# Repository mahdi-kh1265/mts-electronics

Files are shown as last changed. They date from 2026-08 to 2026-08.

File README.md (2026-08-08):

# mts-electronics

Analog RF, photodetector, and demodulation electronics for POSM's modulation-transfer spectroscopy (MTS) laser-locking system.

This repository contains two custom PCBs:

1. **`mts-clk`** — 10 MHz RF distribution and phase-control board for the EOM drive and MTS demodulation local oscillator.
2. **`mts-demod`** — photodiode front end, RF conditioning, analog mixer demodulation, and baseband error-signal generation.

The boards form the analog front end of POSM's rubidium MTS frequency lock.

---

## System Overview

# 1. `mts-clk` — 10 MHz Clock / Phase-Control Board

`mts-clk` takes a common 10 MHz RF source and generates the two coherent RF signals needed by the spectroscopy system:

* **EOM path** — drives the modulation chain associated with the electro-optic modulator.
* **DEMOD path** — provides the coherent local oscillator used by the analog MTS mixer.

Using a common source preserves coherence between modulation and demodulation.

# 2. `mts-demod` — Photodiode and Analog Demodulator

`mts-demod` converts the optical MTS signal into a low-frequency analog error signal suitable for digitization and feedback.

The board includes:

* FDS010 photodiode interface
* reverse-bias circuitry
* OPA858 transimpedance amplifier
* OPA695 second-stage RF amplifier
* 25 MHz RF cleanup filters
* RF splitting / diagnostic outputs
* conditioned 10 MHz LO path
* Mini-Circuits ADE-1+ mixer
* Mini-Circuits PLP-5+ post-mixer low-pass filter
* raw and demodulated monitor outputs

# 3. Repository Structure

```text
mts-electronics/
│
├── mts-clk/
│   ├── mts-clk.kicad_sch
│   ├── mts-clk.kicad_pcb
│   ├── mts-clk.kicad_pro
│   ├── libraries/
│   └── gerbers/
│
├── mts-demod/
│   ├── mts-demod.kicad_sch
│   ├── mts-demod.kicad_pcb
│   ├── mts-demod.kicad_pro
│   └── libraries/
│
├── LICENSE
└── README.md
```

The projects are currently stored in **KiCad 10** format.

---

# 4. Major Components

| Function | Part | Board |
| --- | --- | --- |
| RF power splitter | Mini-Circuits TCP-2-10X | `mts-clk` |
| EOM-path RF amplifier | ADI LTC6433-15 | `mts-clk` |
| DEMOD-path RF amplifier | ADI LTC6433-15 | `mts-clk` |
| Voltage-controlled RF phase shifter | Mini-Circuits SCPHS-13.6+ | `mts-clk` |
| Phase-control buffer | TI OPA197 | `mts-clk` |
| Photodiode | Thorlabs FDS010 | `mts-demod` |
| First-stage TIA | TI OPA858 | `mts-demod` |
| Second-stage amplifier | TI OPA695 | `mts-demod` |
| LO gain block | Mini-Circuits GVA-81 | `mts-demod` |
| Mixer | Mini-Circuits ADE-1+ | `mts-demod` |
| Post-mixer LPF | Mini-Circuits PLP-5+ | `mts-demod` |

Refer to the KiCad schematics for current component values and complete BOM information.

---

# 5. Bring-Up Sequence

These boards should be characterized independently before being connected to the complete laser lock.

## `mts-clk`

1. Verify resistance from each supply rail to ground before applying power.
2. Power the board with no external RF connections.
3. Verify all supply rails and amplifier bias conditions.
4. Apply a known 10 MHz RF input.
5. Measure the EOM output with an oscilloscope or spectrum analyzer.
6. Measure the DEMOD output.
7. Sweep the analog phase-control voltage.
8. Verify phase variation at 10 MHz relative to the EOM output.
9. Verify output amplitude remains within the intended range across the useful phase-control range.
10. Characterize phase versus control voltage and save the calibration curve.

## `mts-demod`

1. Verify all power rails before installing/connecting sensitive external hardware.
2. Verify photodiode reverse bias.
3. Illuminate the FDS010 with a controlled optical signal.
4. Measure the OPA858 TIA output.
5. Verify the OPA695 second-stage gain.
6. Verify the 25 MHz cleanup-filter response.
7. Apply a known 10 MHz DEMOD/LO signal.
8. Verify the GVA-81 LO chain.
9. Verify adequate LO drive at the ADE-1+.
10. Observe the raw mixer IF.
11. Verify the PLP-5+ output.
12. Sweep relative RF/LO phase and confirm the expected quadrature dependence.
13. Only after analog characterization, connect the ADC / FPGA system.

---

# 10. Characterization Data to Add

The schematic captures the intended design. Measured hardware performance should be added separately once boards are assembled.

Useful measurements include:

### CLK board

* EOM output power at 10 MHz
* DEMOD output power at 10 MHz
* EOM-to-DEMOD relative phase range
* phase versus control voltage
* amplitude versus phase-control voltage
* harmonic distortion
* broadband noise
* output return loss / matching

### DEMOD board

* TIA transimpedance
* TIA noise spectral density
* complete photodiode-path gain
* 25 MHz filter response
* mixer conversion gain/loss
* LO level at ADE-1+
* baseband transfer function
* analog error-signal noise
* output offset
* usable MTS discriminator slope
* channel saturation limits

Measured data should eventually be stored under a dedicated directory such as:

```text
measurements/
├── mts-clk/
│   ├── phase_vs_control_voltage.csv
│   ├── output_spectrum/
│   └── network_analyzer/
│
└── mts-demod/
    ├── tia_noise/
    ├── rf_transfer_function/
    ├── mixer_characterization/
    └── mts_error_signal/
```
# License

Released under the license included in [`LICENSE`](LICENSE).

---

## POSM

**Photonics and Optical Sciences Club at Minnesota**
University of Minnesota

[POSM website](https://posmphotonics.org/)

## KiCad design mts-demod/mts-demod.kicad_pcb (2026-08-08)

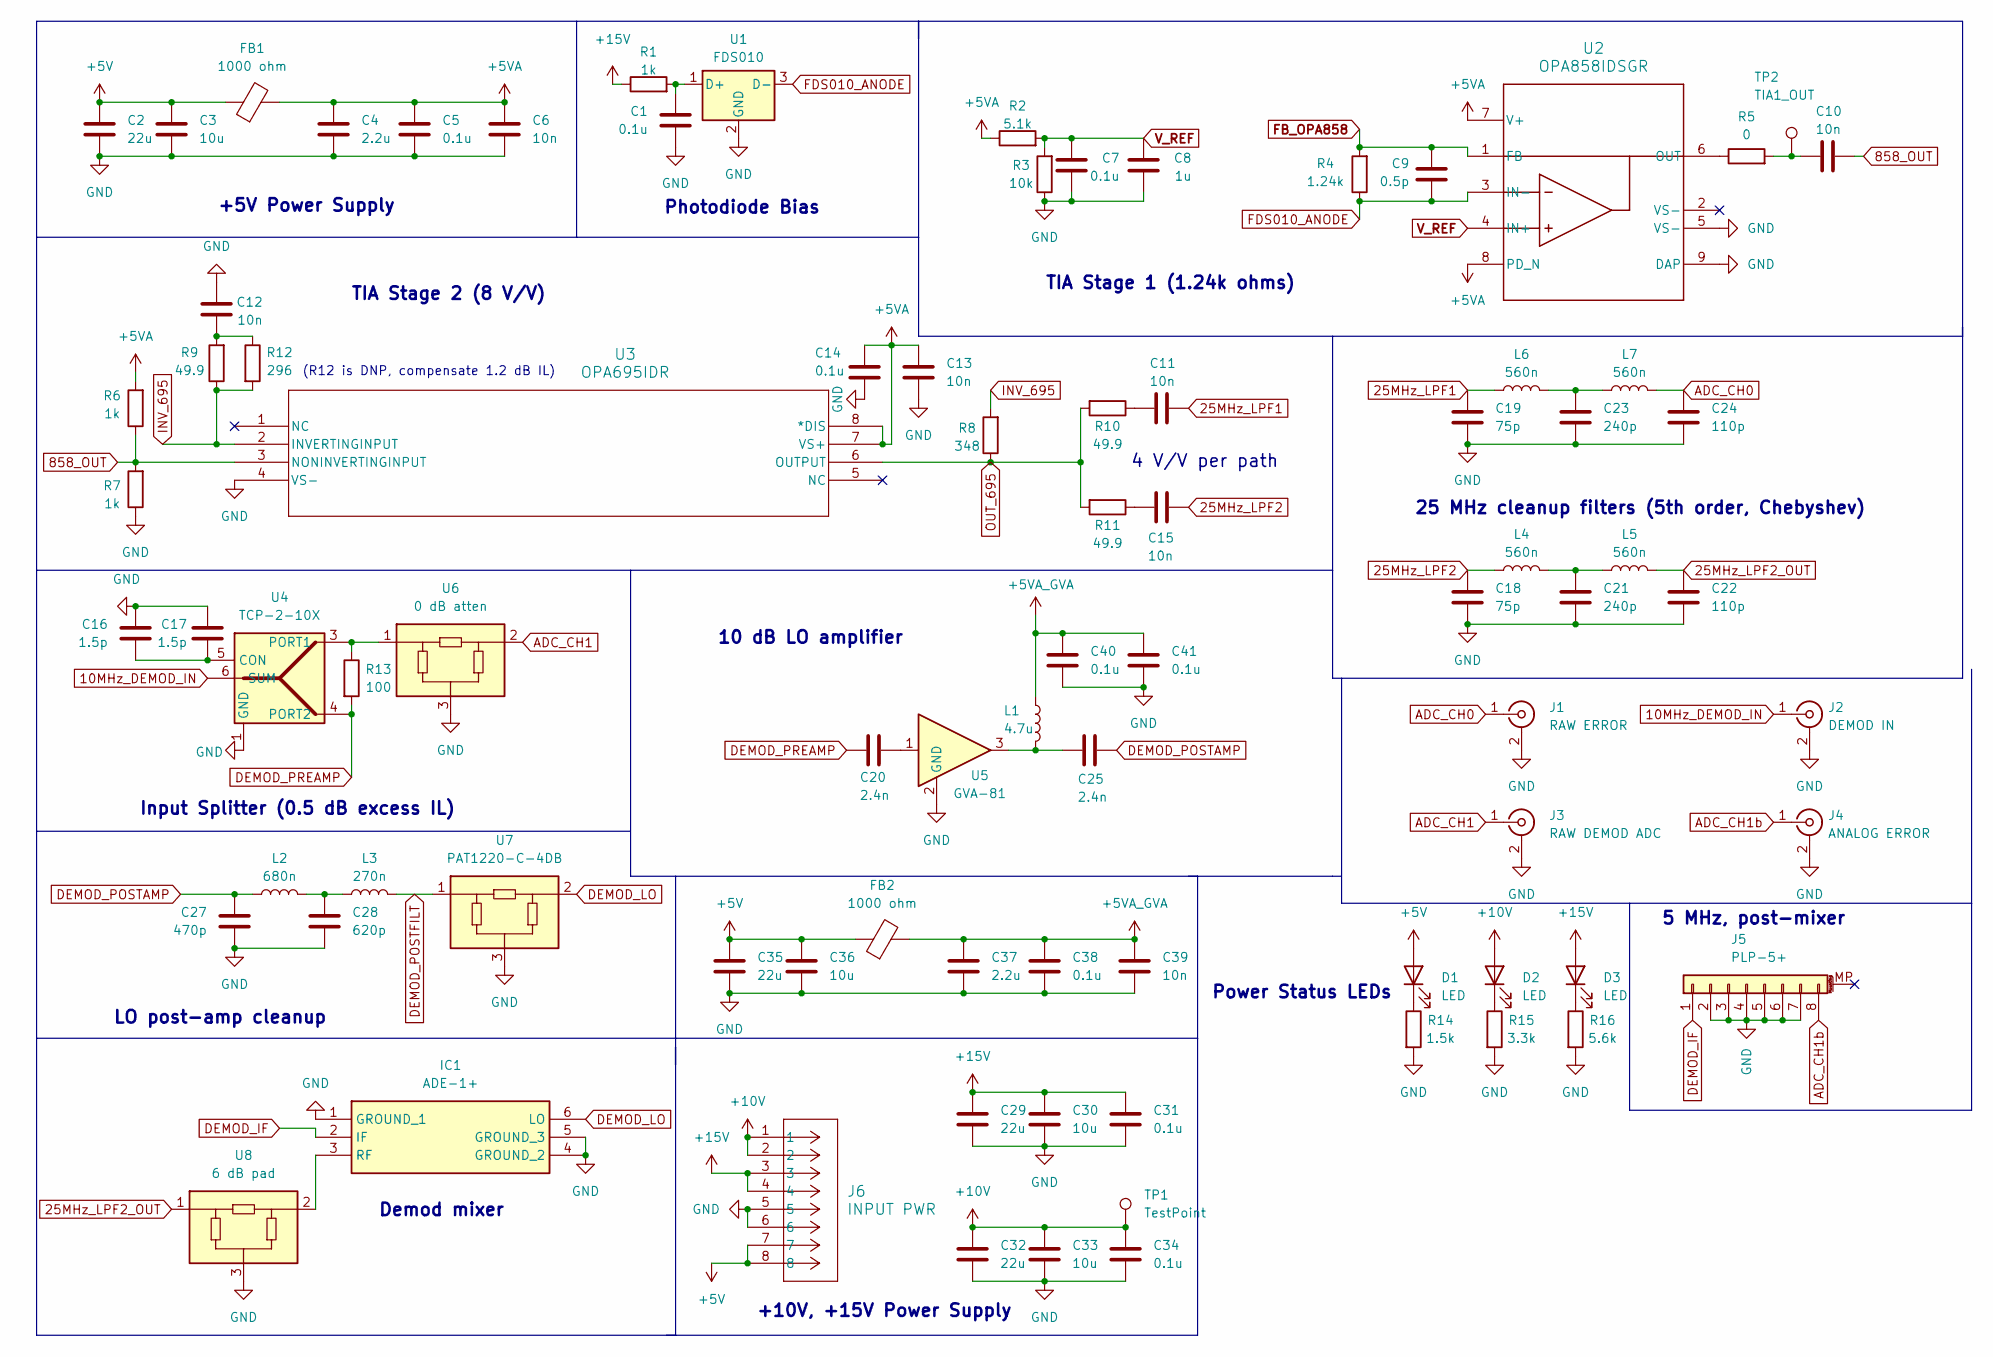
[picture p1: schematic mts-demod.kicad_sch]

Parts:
C1, C5, C7, C14, C31, C34, C38, C40, C41: 0.1u; C_0603_1608Metric
C2, C29, C32, C35: 22u; C_0805_2012Metric
C3, C30, C33, C36: 10u; C_0805_2012Metric
C4, C37: 2.2u; C_0603_1608Metric
C6, C10, C11, C12, C13, C15, C39: 10n; C_0402_1005Metric
C8: 1u; C_0603_1608Metric
C9: 0.5p; C_0402_1005Metric
C16, C17: 1.5p; C_0402_1005Metric
C18: 75p; C_0805_2012Metric
C19: 75p; C_0402_1005Metric
C20, C25: 2.4n; C_0402_1005Metric
C21: 240p; C_0805_2012Metric
C22: 110p; C_0805_2012Metric
C23: 240p; C_0402_1005Metric
C24: 110p; C_0402_1005Metric
C27: 470p; C_0805_2012Metric
C28: 620p; C_0805_2012Metric
D1, D2, D3: LED; LED_0603_1608Metric
FB1, FB2: 1000 ohm; L_0805_2012Metric
IC1: ADE-1+; ADE1; Mouser Part Number 139-ADE-1
J1: RAW ERROR; CONN_SMA-J-P-H-ST-TH1_SAI
J2: DEMOD IN; CONN_SMA-J-P-H-ST-TH1_SAI
J3: RAW DEMOD ADC; CONN_SMA-J-P-H-ST-TH1_SAI
J4: ANALOG ERROR; CONN_SMA-J-P-H-ST-TH1_SAI
J5: PLP-5+; MINI-CIRCUITS_A01_CERN
J6: INPUT PWR; CONN_SD-43045-005_08_MOL
L1: 4.7u; L_0603_1608Metric
L2: 680n; L_0805_2012Metric
L3: 270n; L_0805_2012Metric
L4, L5, L6, L7: 560n; L_0805_2012Metric
R1, R6, R7: 1k; C_0603_1608Metric
R2: 5.1k; R_0603_1608Metric
R3: 10k; R_0603_1608Metric
R4: 1.24k; R_0603_1608Metric
R5: 0; R_0402_1005Metric
R8: 348; R_0402_1005Metric
R9: 49.9; C_0603_1608Metric
R10, R11: 49.9; R_0402_1005Metric
R12: 296; C_0603_1608Metric
R13: 100; C_0603_1608Metric
R14: 1.5k; C_0603_1608Metric
R15: 3.3k; C_0603_1608Metric
R16: 5.6k; C_0603_1608Metric
TP1: TestPoint; TestPoint_Keystone_5015_Micro_Mini
TP2: TIA1_OUT; TestPoint_Keystone_5015_Micro_Mini
U1: FDS010; TO-39-3
U2: OPA858IDSGR; DSG0008A
U3: OPA695IDR; D8
U4: TCP-2-10X; Mini-Circuits_DB1627
U5: GVA-81; SOT-89-3
U6: 0 dB atten; RF_Attenuator_Susumu_PAT1220
U7: PAT1220-C-4DB; RF_Attenuator_Susumu_PAT1220
U8: 6 dB pad; RF_Attenuator_Susumu_PAT1220

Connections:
10MHz_DEMOD_IN: J2.1 (In), U4.6 (SUM)
25MHz_LPF1: C11.2, C19.1, L6.1
25MHz_LPF2: C15.2, C18.1, L4.1
25MHz_LPF2_OUT: C22.1, L5.2, U8.1
858_OUT: C10.2, R6.1, R7.2, U3.3 (NONINVERTINGINPUT)
+5V: C2.1, C3.1, C35.1, C36.1, D1.2 (A), FB1.1, FB2.1, J6.7, J6.8; also elsewhere on the board
+5VA: C4.1, C5.1, C6.1, C13.1, C14.2, FB1.2, R2.1, R6.2, U2.7 (V+), U2.8 (PD_N), U3.7 (VS+), U3.8 (*DIS)
+5VA_GVA: C37.1, C38.1, C39.1, C40.1, C41.1, FB2.2, L1.1
+10V: C32.1, C33.1, C34.1, D2.2 (A), J6.1, J6.2, TP1.1; also elsewhere on the board
+15V: C29.1, C30.1, C31.1, D3.2 (A), J6.3, J6.4, R1.1; also elsewhere on the board
ADC_CH0: C24.1, J1.1 (In), L7.2
ADC_CH1: J3.1 (In), U6.2
ADC_CH1b: J4.1 (In), J5.8
DEMOD_IF: IC1.2 (IF), J5.1
DEMOD_LO: IC1.6 (LO), U7.2
DEMOD_POSTAMP: C25.1, C27.2, L2.1
DEMOD_POSTFILT: L3.2, U7.1
DEMOD_PREAMP: C20.2, R13.2, U4.4 (PORT2)
FB_OPA858: C9.2, R4.2, U2.1 (FB)
FDS010_ANODE: C9.1, R4.1, U1.3 (D-), U2.3 (IN-)
GND: C1.2, C2.2, C3.2, C4.2, C5.2, C6.2, C7.2, C8.2, C12.1, C13.2, C14.1, C16.2, C17.2, C18.2, C19.2, C21.2, C22.2, C23.2, C24.2, C27.1, C28.1, C29.2, C30.2, C31.2, C32.2, C33.2, C34.2, C35.2, C36.2, C37.2, C38.2, C39.2, C40.2, C41.2, IC1.1 (GROUND_1), IC1.4 (GROUND_2), IC1.5 (GROUND_3), J1.2 (Ext), J1.3, J1.4, J1.5, J2.2 (Ext), J2.3, J2.4, J2.5, J3.2 (Ext), J3.3, J3.4, J3.5, J4.2 (Ext), J4.3, J4.4, J4.5, J5.2, J5.3, J5.4, J5.5, J5.6, J5.7, J6.5, J6.6, R3.1, R7.1, R14.2, R15.2, R16.2, U1.2 (GND), U2.5 (VS-), U2.9 (DAP), U3.4 (VS-), U4.1 (GND), U5.2 (GND_2), U6.3, U7.3, U8.3
INV_695: R8.2, R9.1, R12.2, U3.2 (INVERTINGINPUT)
unnamed 22: C10.1, R5.2, TP2.1; also elsewhere on the board
unnamed: C11.1, R10.1
unnamed: C12.2, R9.2, R12.1
unnamed: C15.1, R11.1
unnamed: C20.1, U5.1
unnamed: C21.1, L4.2, L5.1
unnamed: C23.1, L6.2, L7.1
unnamed: C25.2, L1.2, U5.3
unnamed: C28.2, L2.2, L3.1
unnamed 31: D1.1 (K), R14.1; also elsewhere on the board
unnamed 32: D2.1 (K), R15.1; also elsewhere on the board
unnamed 33: D3.1 (K), R16.1; also elsewhere on the board
unnamed: IC1.3 (RF), U8.2
unnamed: C1.1, R1.2, U1.1 (D+)
unnamed: R5.1, U2.6 (OUT)
unnamed: R13.1, U4.3 (PORT1), U6.1
OUT_695: R8.1, R10.2, R11.2, U3.6 (OUTPUT)
V_REF: C7.1, C8.1, R2.2, R3.2, U2.4 (IN+)

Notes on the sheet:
(R12 is DNP, compensate 1.2 dB IL)
+10V, +15V Power Supply
+5V Power Supply
Photodiode Bias
Power Status LEDs
25 MHz cleanup filters (5th order, Chebyshev)
10 dB LO amplifier
4 V/V per path
LO post-amp cleanup
TIA Stage 2 (8 V/V)
TIA Stage 1 (1.24k ohms)
5 MHz, post-mixer
Input Splitter (0.5 dB excess IL)
Demod mixer

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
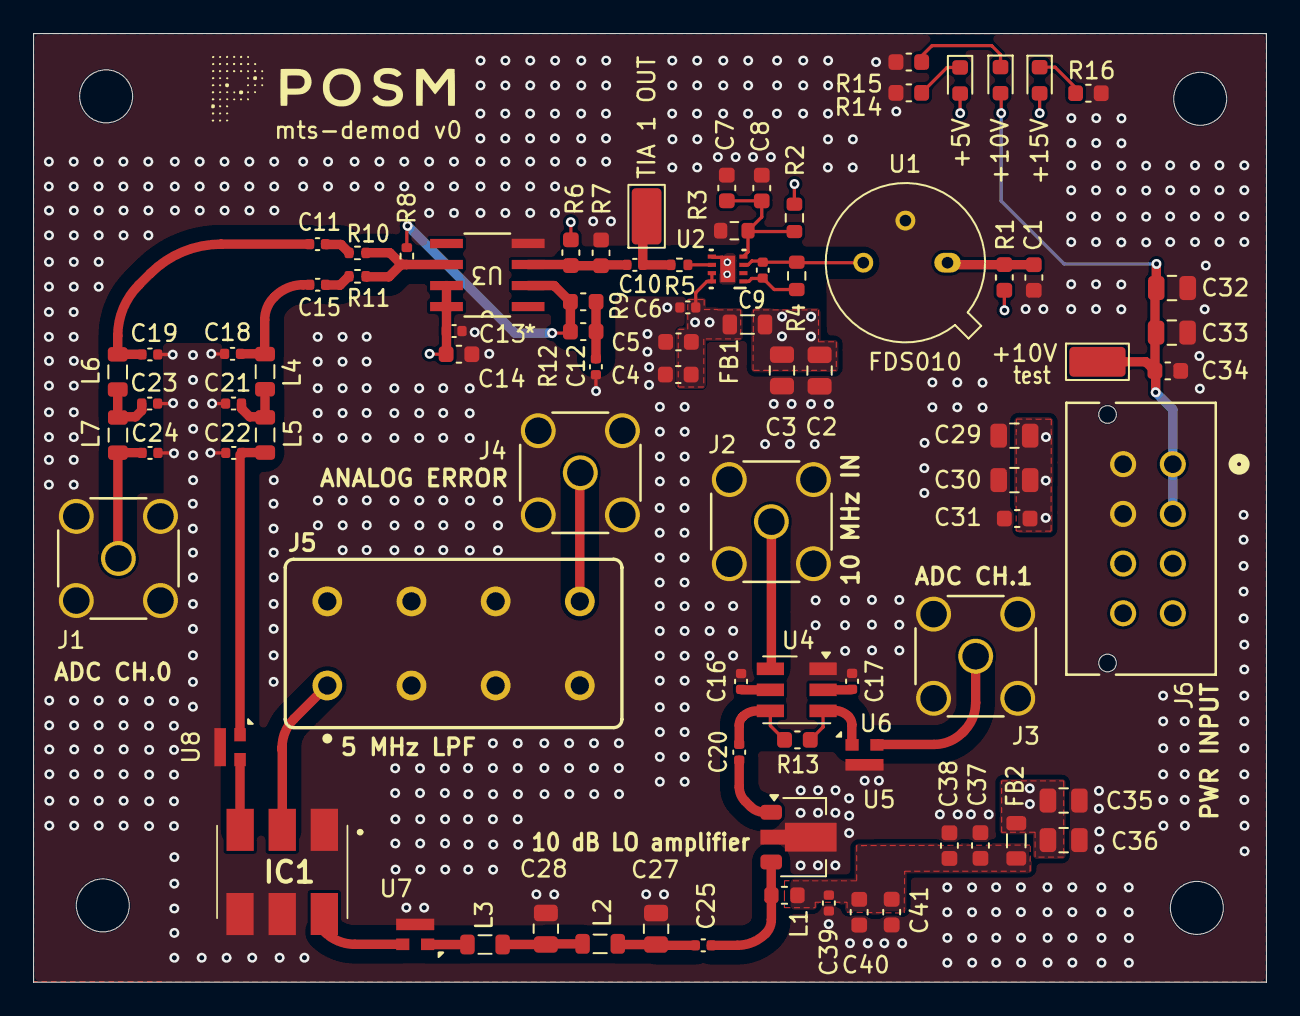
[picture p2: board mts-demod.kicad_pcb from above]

Board: 4 copper layers, 74.4 x 57.3 mm, 85 parts (0 on the bottom side), 42 nets.

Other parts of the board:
+5V, +10V#2, +15V: LED; LED_0603_1608Metric
+10V: TestPoint; TestPoint_Keystone_5015_Micro_Mini
TIA 1 OUT: TIA1_OUT; TestPoint_Keystone_5015_Micro_Mini

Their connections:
+5V: +5V.2 (A); also elsewhere on the board
+10V: +10V.1 (1_1), +10V#2.2 (A); also elsewhere on the board
+15V: +15V.2 (A); also elsewhere on the board
unnamed 22: TIA 1 OUT.1 (1_1); also elsewhere on the board
unnamed 31: +5V.1 (K); also elsewhere on the board
unnamed 32: +10V#2.1 (K); also elsewhere on the board
unnamed 33: +15V.1 (K); also elsewhere on the board

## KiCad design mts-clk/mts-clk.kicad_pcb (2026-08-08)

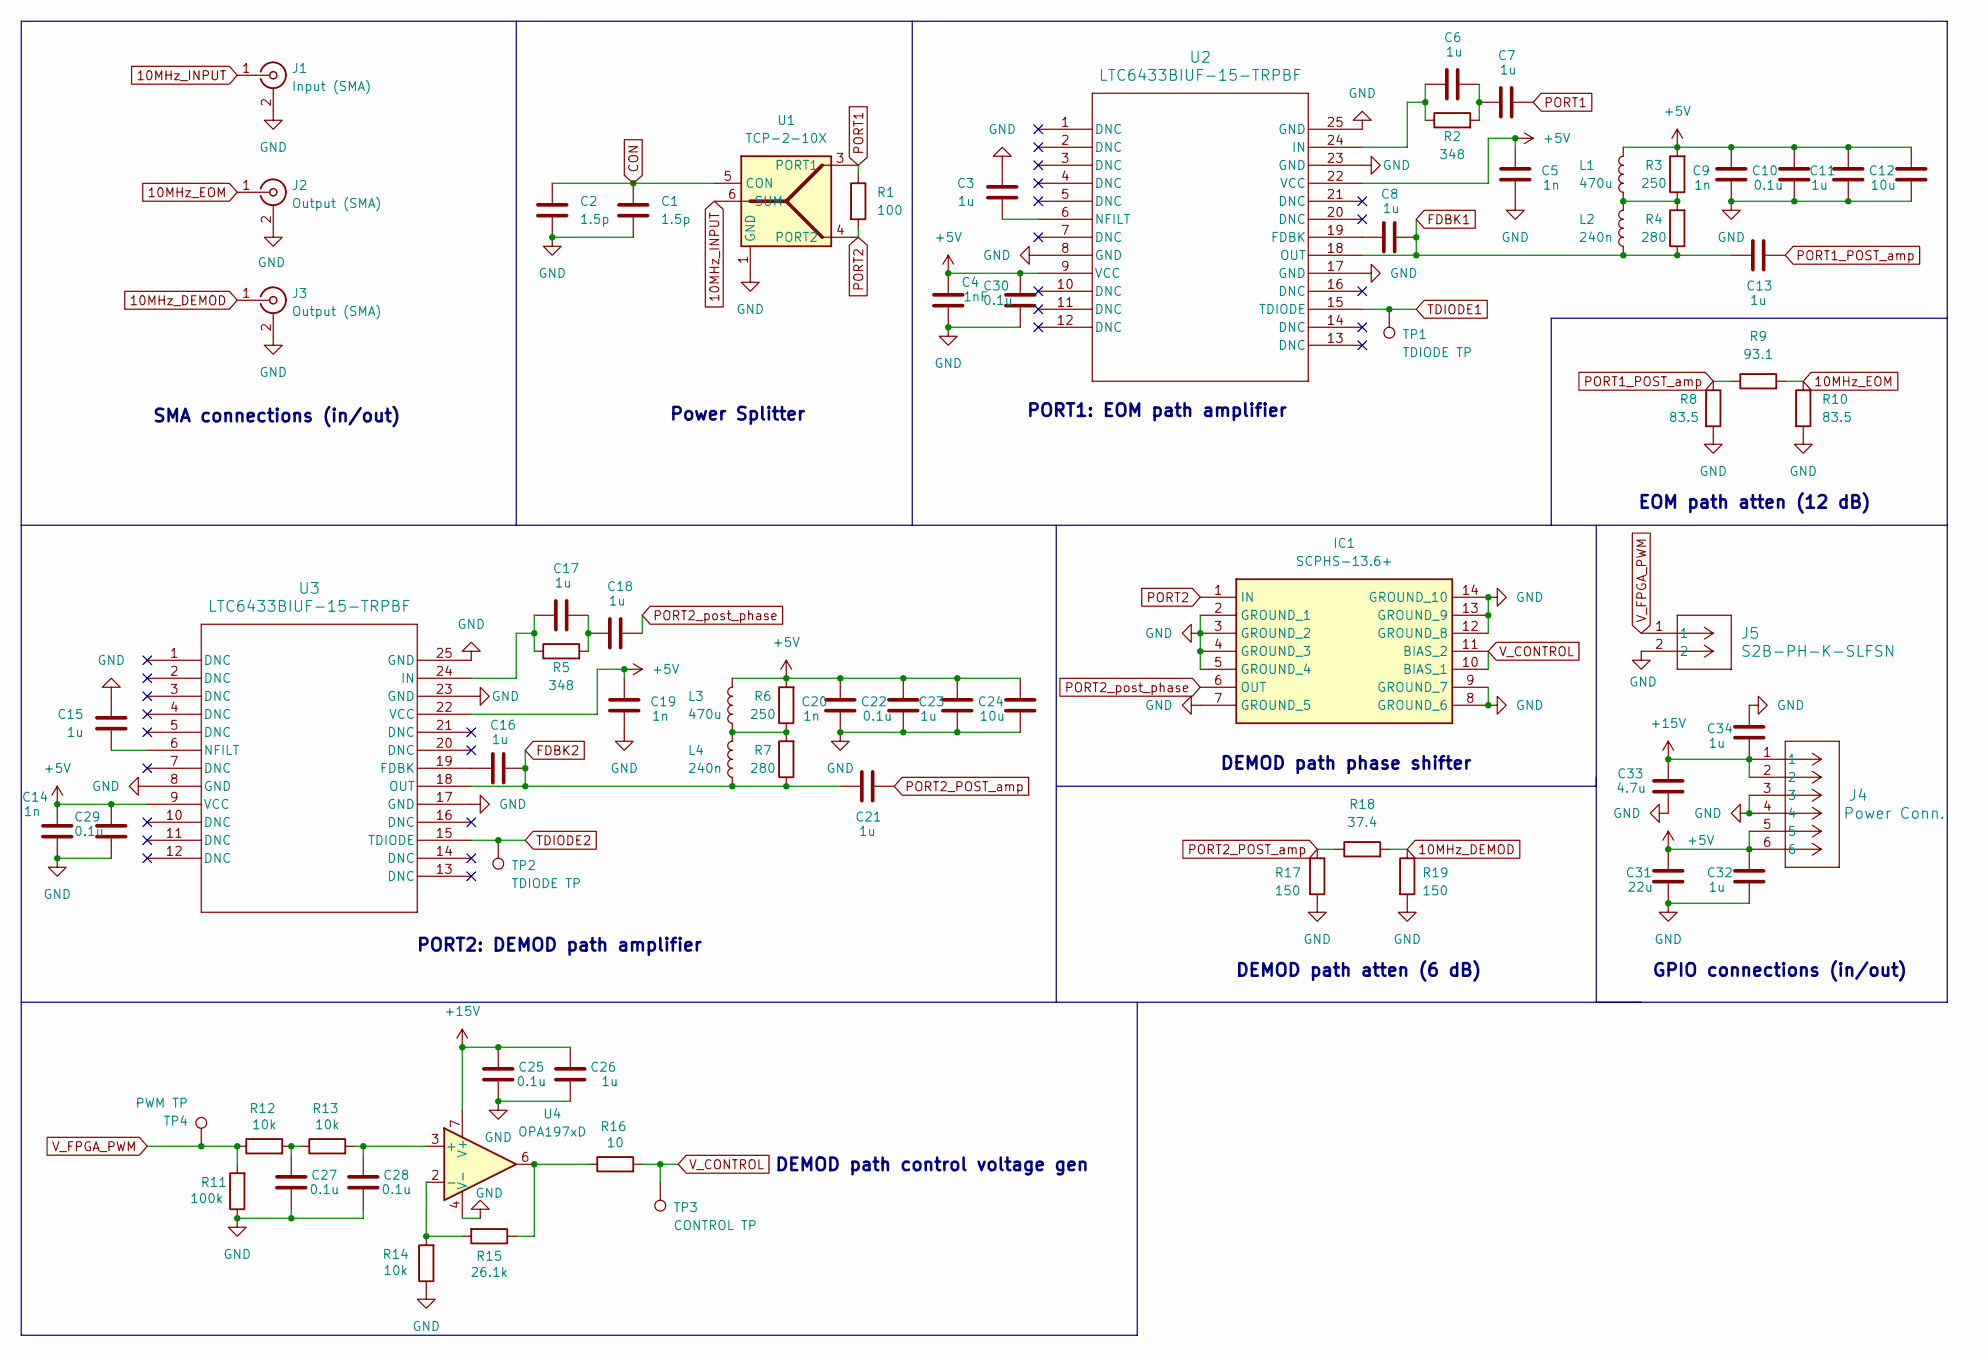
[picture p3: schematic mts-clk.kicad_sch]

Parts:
C1, C2: 1.5p; C_0402_1005Metric
C3, C6, C7, C8, C11, C13, C15, C16, C17, C18, C21, C23, C26: 1u; C_0805_2012Metric
C4: 1nF; C_0402_1005Metric
C5, C9, C14, C19, C20: 1n; C_0402_1005Metric
C10, C22, C29, C30: 0.1u; C_0603_1608Metric
C12, C24: 10u; C_0805_2012Metric
C25, C27, C28: 0.1u; C_0805_2012Metric
C31: 22u; C_1206_3216Metric
C32, C34: 1u; C_0603_1608Metric
C33: 4.7u; C_1206_3216Metric
IC1: SCPHS-13.6+; SCPHS136; Manufacturer_Part_Number SCPHS-13.6+
J1: Input (SMA); CONN_SMA-J-P-H-ST-TH1_SAI
J2, J3: Output (SMA); CONN_SMA-J-P-H-ST-TH1_SAI
J4: Power Conn.; CONN_SD-43045-005_06_MOL
J5: S2B-PH-K-SLFSN; CONN_S2B-PH-K-S_JST
L1, L3: 470u; L_Coilcraft_LPS5030
L2, L4: 240n; L_0603_1608Metric
R1: 100; R_0603_1608Metric
R2, R5: 348; R_0805_2012Metric
R3, R6: 250; R_0603_1608Metric
R4, R7: 280; R_0603_1608Metric
R8, R10: 83.5; R_0603_1608Metric
R9: 93.1; R_0603_1608Metric
R11: 100k; R_0603_1608Metric
R12, R13, R14: 10k; R_0603_1608Metric
R15: 26.1k; R_0603_1608Metric
R16: 10; R_0603_1608Metric
R17, R19: 150; R_0603_1608Metric
R18: 37.4; R_0603_1608Metric
TP1, TP2: TDIODE TP; TestPoint_Keystone_5015_Micro_Mini
TP3: CONTROL TP; TestPoint_Keystone_5015_Micro_Mini
TP4: PWM TP; TestPoint_Keystone_5015_Micro_Mini
U1: TCP-2-10X; Mini-Circuits_DB1627
U2, U3: LTC6433BIUF-15-TRPBF; UF_24_ADI
U4: OPA197xD; SOIC-8_3.9x4.9mm_P1.27mm

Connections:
10MHz_DEMOD: J3.1 (In), R18.2, R19.1
10MHz_EOM: J2.1 (In), R9.2, R10.1
10MHz_INPUT: J1.1 (In), U1.6 (SUM)
+5V: C4.2, C5.2, C9.2, C10.2, C11.2, C12.2, C14.2, C19.2, C20.2, C22.2, C23.2, C24.2, C29.2, C30.2, C31.2, C32.2, J4.5, J4.6, L1.2, L3.2, R3.2, R6.2, U2.9 (VCC), U2.22 (VCC), U3.9 (VCC), U3.22 (VCC)
+15V: C25.1, C26.1, C33.1, C34.1, J4.1, J4.2, U4.7 (V+)
FDBK1: C8.1, C13.2, L2.1, R4.1, U2.18 (OUT)
FDBK2: C16.1, C21.2, L4.1, R7.1, U3.18 (OUT)
GND: C1.2, C2.1, C3.1, C4.1, C5.1, C9.1, C10.1, C11.1, C12.1, C14.1, C15.1, C19.1, C20.1, C22.1, C23.1, C24.1, C25.2, C26.2, C27.2, C28.2, C29.1, C30.1, C31.1, C32.1, C33.2, C34.2, IC1.2 (GROUND_1), IC1.3 (GROUND_2), IC1.4 (GROUND_3), IC1.5 (GROUND_4), IC1.7 (GROUND_5), IC1.8 (GROUND_6), IC1.9 (GROUND_7), IC1.12 (GROUND_8), IC1.13 (GROUND_9), IC1.14 (GROUND_10), J1.2 (Ext), J1.3, J1.4, J1.5, J2.2 (Ext), J2.3, J2.4, J2.5, J3.2 (Ext), J3.3, J3.4, J3.5, J4.3, J4.4, J5.2, R8.2, R10.2, R11.1, R14.1, R17.2, R19.2, U1.1 (GND), U2.8 (GND), U2.17 (GND), U2.23 (GND), U2.25 (GND), U3.8 (GND), U3.17 (GND), U3.23 (GND), U3.25 (GND), U4.4 (V-)
unnamed: C6.1, C7.2, R2.2
unnamed: C17.1, C18.2, R5.2
unnamed: C27.1, R12.2, R13.1
unnamed: L1.1, L2.2, R3.1, R4.2
unnamed: L3.1, L4.2, R6.1, R7.2
unnamed: R15.1, R16.1, U4.6
unnamed: C8.2, U2.19 (FDBK)
unnamed: C6.2, R2.1, U2.24 (IN)
unnamed: C3.2, U2.6 (NFILT)
unnamed: C16.2, U3.19 (FDBK)
unnamed: C17.2, R5.1, U3.24 (IN)
unnamed: C15.2, U3.6 (NFILT)
unnamed: C28.1, R13.2, U4.3 (+)
unnamed: R14.2, R15.2, U4.2 (-)
PORT1: C7.1, R1.1, U1.3 (PORT1)
PORT1_POST_amp: C13.1, R8.1, R9.1
PORT2: IC1.1 (IN), R1.2, U1.4 (PORT2)
PORT2_POST_amp: C21.1, R17.1, R18.1
PORT2_post_phase: C18.1, IC1.6 (OUT)
TDIODE1: TP1.1 (1_1), U2.15 (TDIODE)
TDIODE2: TP2.1 (1_1), U3.15 (TDIODE)
V_CONTROL: IC1.10 (BIAS_1), IC1.11 (BIAS_2), R16.2, TP3.1 (1_1)
V_FPGA_PWM: J5.1, R11.2, R12.1, TP4.1 (1_1)

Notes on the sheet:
PORT1: EOM path amplifier
SMA connections (in/out)
DEMOD path phase shifter
DEMOD path control voltage gen
DEMOD path atten (6 dB)
GPIO connections (in/out)
Power Splitter
EOM path atten (12 dB)
PORT2: DEMOD path amplifier

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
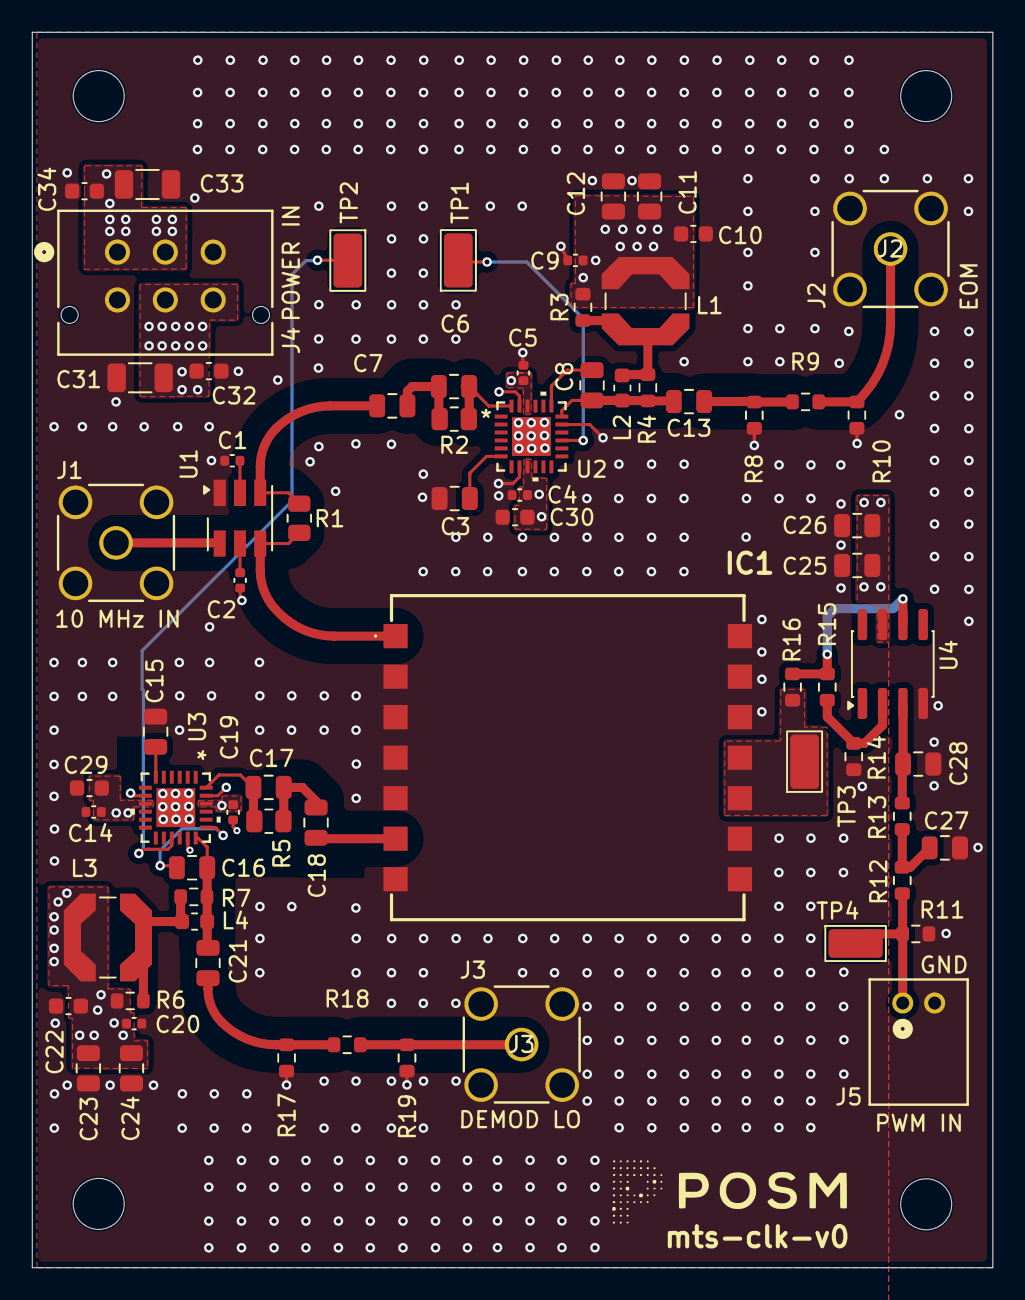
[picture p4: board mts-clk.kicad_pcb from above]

Board: 4 copper layers, 60.2 x 77.5 mm, 71 parts (0 on the bottom side), 33 nets.

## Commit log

2026-07-27 finished sch
    [mts-clk.kicad_pcb, mts-clk.kicad_sch]
2026-07-27 fixed atten issue
    [mts-clk.kicad_sch]
2026-07-27 final changes to CLK sch
    [mts-clk.kicad_sch]
2026-07-27 layout for demod and drive
    [mts-clk.kicad_pcb]
2026-07-28 layout for CLK
    [mts-clk.kicad_pcb, mts-clk.kicad_sch]
2026-07-28 added kicad entries for gitignore
2026-07-28 idek man
    [mts-clk.kicad_pcb]
2026-07-28 Remove KiCad and editor history entries from .gitignore
2026-07-28 complete with mts-clk v0 layout
    [mts-clk.kicad_pcb]
2026-07-28 final final
    [mts-clk.kicad_pcb]
2026-07-28 final final final
    [mts-clk.kicad_pcb]
2026-07-28 adding mounting holes, more stitching
    [mts-clk.kicad_pcb]
2026-07-28 fixed pour hierarchy
    [mts-clk.kicad_pcb]
2026-07-28 finally, added labels, fixed mask/paste issues
    [mts-clk.kicad_pcb]
2026-07-28 completely done! zipped gbrs
    [mts-clk-B_Cu.gbl, mts-clk-B_Mask.gbs, mts-clk-B_Paste.gbp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]
2026-07-28 fixed repo hierarchy for next proj
    [mts-clk-B_Cu.gbl, mts-clk-B_Mask.gbs, mts-clk-B_Paste.gbp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]
2026-07-29 demod circuit sch
    [mts-demod.kicad_pcb, mts-demod.kicad_sch]
2026-07-29 completed stage two of TIA
    [mts-demod.kicad_sch]
2026-07-30 almost done with demod sch
    [mts-demod.kicad_sch]
2026-07-30 demod sch is complete
    [mts-demod.kicad_sch]
2026-07-30 init layout, pwr sections
    [mts-demod.kicad_sch]
2026-07-31 the most elegant board that i've ever laid out
    [mts-demod.kicad_pcb, mts-demod.kicad_sch]
2026-07-31 finished layout for demod
    [mts-demod.kicad_pcb]
2026-08-01 added more stitch and thermals
    [mts-demod.kicad_pcb]
2026-08-01 tiny error on 858
    [mts-demod.kicad_pcb]
2026-08-01 fixed GND return under OPA858
    [mts-demod.kicad_pcb]
2026-08-01 vias under 858 were wrong
    [mts-demod.kicad_pcb]
2026-08-01 final final final? for demod
    [mts-demod.kicad_pcb]
2026-08-08 Jack's three vias
    [mts-clk.kicad_pcb, mts-clk.kicad_sch]
2026-08-08 more Jack-ias
    [mts-demod.kicad_pcb]
2026-08-08 added gerbers
    [mts-clk-B_Cu.gbl, mts-clk-B_Mask.gbs, mts-clk-B_Paste.gbp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]
2026-08-08 added demod gerbers
    [mts-demod-B_Cu.gbr, mts-demod-B_Mask.gbr, mts-demod-B_Paste.gbr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]
